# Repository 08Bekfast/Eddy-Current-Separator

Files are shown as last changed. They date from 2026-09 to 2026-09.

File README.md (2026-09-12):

# Miniaturized Eddy Current Separator

A compact, conveyor-based prototype for automatically separating non-ferrous metals from mixed material streams using electromagnetic induction.

**Project period:** November 2024 - January 2025  

<p align="center">
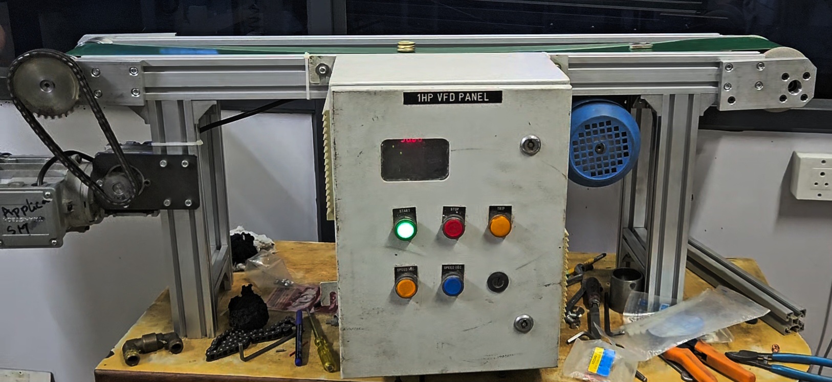
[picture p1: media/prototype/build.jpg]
Fabricated components and magnetic roller assembly
  
</p>

## How it works

Material travels along a conveyor and passes over a high-speed permanent-magnet rotor. The rotor produces a rapidly changing magnetic field, which induces eddy currents in conductive, non-ferrous pieces. Their opposing magnetic field creates a repulsive force, throwing them farther than non-conductive material and enabling physical separation.

## System overview

| Subsystem | Implementation |
|---|---|
| Structure | Aluminium extrusion frame with machined brackets and bearing mounts |
| Separation | Magnetic rotor inside a smooth PVC outer shell beneath a PU-coated conveyor belt |
| Drivetrain | Two three-phase motors, chain/sprocket transmission, 15:1 gearbox, and 1 HP VFD |
| Sensing | 20 kg load cell, HX711 amplifier, ultrasonic bin-level sensor |
| Control and telemetry | Arduino Uno, HC-05 Bluetooth module, and MIT App Inventor interface |
| Mechanical design | AutoCAD fabrication drawings and Fusion 360 component models/renders |

## Test results

Tests used approximately 1 cm² samples with a thickness of 1 mm.

| Material | Density (g/cm³) | Conductivity (MS/m) | Measured throw distance (m) |
|---|---:|---:|---:|
| Aluminium | 2.7 | ~37 | 1.25-1.70 |
| Copper | 8.96 | ~58 | 1.00-1.60 |
| Brass | ~8.5 | ~15 | 0.90-1.50 |

The prototype separated aluminium, copper, and brass samples in multiple shapes, including plates, rings, spheres, and folded wire. Thicker copper pieces were less consistent because their higher mass required greater ejection force. The sensing subsystem also delivered calibrated, real-time weight readings to the mobile app.

## CAD previews

| Outer-shell flange | Magnetic-roller shaft flange |
|---|---|
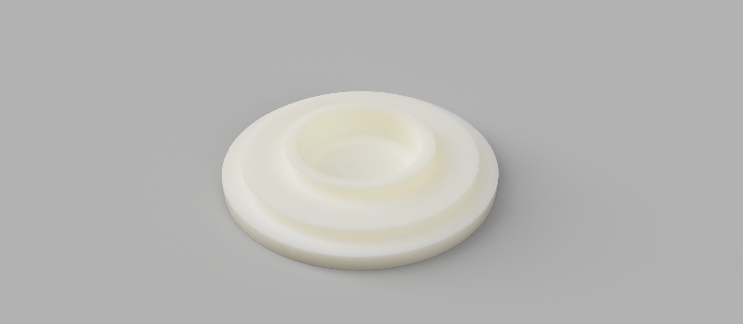
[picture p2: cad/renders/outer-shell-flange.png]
Outer-shell flange render
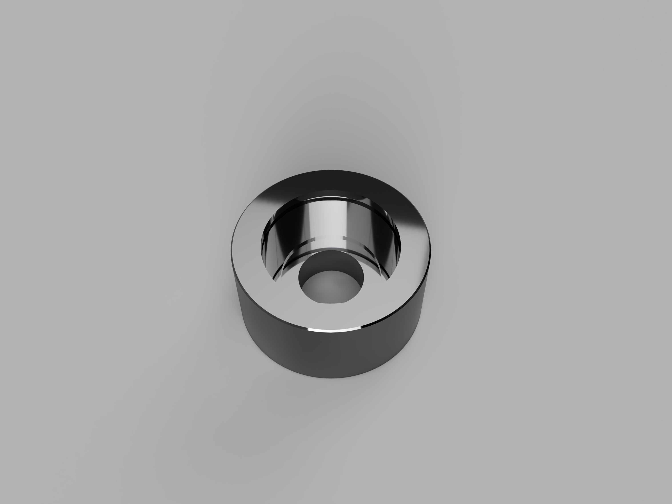
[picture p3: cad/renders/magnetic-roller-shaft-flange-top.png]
Magnetic-roller shaft flange render
|  |  |

| Shaft flange underside | Magnetic-shaft side bracket |
|---|---|
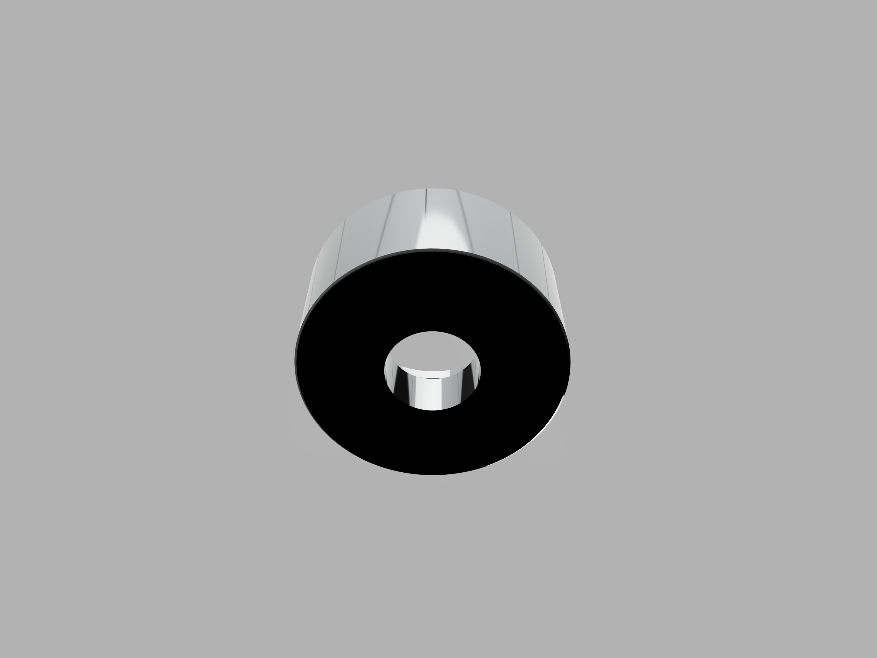
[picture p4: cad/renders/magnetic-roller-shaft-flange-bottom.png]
Shaft flange underside
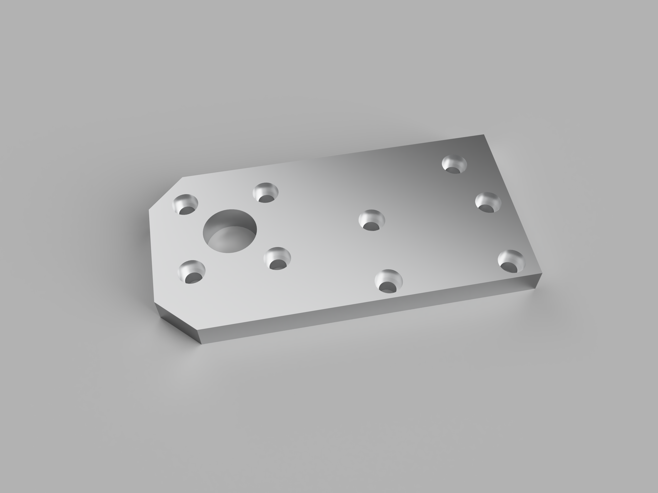
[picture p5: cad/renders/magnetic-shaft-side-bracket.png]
Magnetic-shaft side bracket
|  |  |

## Prototype gallery

The current gallery contains the fabrication and component collage above. Add final assembly, operating, and sorted-output photographs to [`media/prototype`](media/prototype/) using the guide in that folder.

## Repository contents

```text
.
├── cad/
│   ├── drawings/       # Eight dimensioned fabrication drawings
│   ├── models/         # Placeholder for native/neutral 3D CAD exports
│   ├── renders/        # Fusion 360 component renders
│   └── source/         # Original AutoCAD DWG
├── media/prototype/    # Physical build photographs
└── README.md
```

- [Full project report](docs/project-report.pdf)
- [CAD file guide](cad/README.md)
- [3D model upload guide](cad/models/README.md)
- [Original AutoCAD drawing](cad/source/eddy-current-separator.dwg)

## Future improvements

- Switch to an Electromagnet based system
- Measure separation efficiency, purity, throughput, and power consumption over larger test sets.

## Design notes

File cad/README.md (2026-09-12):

# CAD files

## Source

- `source/eddy-current-separator.dwg` - original AutoCAD drawing supplied for the project.

## Fabrication drawings

1. Magnetic roller shaft
2. Belt drive roller
3. PVC outer shell
4. Nylon outer-shell flange
5. Magnetic roller shaft flange
6. Idle roller flange
7. Magnetic roller right-side bracket
8. Magnetic roller left-side bracket

## Renders

The `renders/` folder contains Fusion 360 images of the outer-shell flange, magnetic roller shaft flange, and magnetic-shaft side bracket.

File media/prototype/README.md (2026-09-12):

# Prototype photo guide

The supplied fabrication collage is already used in the main README. For a stronger GitHub portfolio, add three landscape photographs here:

1. `completed-separator.jpg` - clean three-quarter view of the entire machine.
2. `separator-operating.jpg` - conveyor and magnetic roller during a test.
3. `separated-output.jpg` - input samples and the resulting material streams.

After adding them, uncomment the prepared image links in the main `README.md`.

Avoid showing personal information, workshop paperwork, or unsafe operation in the frame.

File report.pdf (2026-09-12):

# Eddy Current Separator

### Design, Fabrication, and IoT-Integrated Real-Time Monitoring System

Engineering Documentation & Technical Specification

Abstract — This technical report documents the design, fabrication, and experimental evaluation of a modular, benchtop-scale Eddy Current Separator (ECS) equipped with an integrated real-time Internet of Things (IoT) monitoring system. Eddy current separation leverages alternating magnetic fields induced by a high-speed permanent magnet rotor to generate opposing Lorentz forces in conductive non-ferrous particles, deflecting them away from non-conductive and ferrous bulk streams. The prototype integrates an adjustable conveyor drive system, an internal insulated permanent magnet rotor assembly, and an embedded sensing subsystem utilizing an Arduino microcontroller, an HX711-amplified load cell for continuous material mass logging, and an ultrasonic sensor for bin level monitoring. Telemetry is streamed wirelessly via an HC-05 Bluetooth transceiver to a dedicated Android supervisory dashboard. Empirical tests performed on aluminum, copper, and brass test specimens validate separation deflections between 0.9 m and 1.7 m. A comprehensive breakdown of mechanical drafting, bill of materials, circuit topology, assembly procedures, operational bottlenecks, and resolutions is provided to support open reproducibility.

December 2024

Open-Source Hardware Documentation Archive

### Contents

1 Introduction | 1
2 Problem Definition | 1
3 Literature Review | 2
4 Project Objectives | 3
5 System Architecture and Methodology | 3
6 Engineering Tools and Techniques | 4
7 Prototype Fabrication and Mechanical Assembly | 6
8 Electronics, Sensing, and Supervisory App | 9
9 Experimental Results and Discussion | 12
10 Conclusion and Future Scope | 13

i

Eddy Current Separator — Engineering Documentation | Technical Report

### 1 Introduction

### 1.1 Background

Industrial waste segregation and resource recovery represent critical challenges in municipal and scrap management ecosystems worldwide. Projected global municipal solid waste generation is expected to rise by over 70% by 2050. Despite the urgent need for recycling, low recovery rates persist in developing regions due to financial and operational constraints. Recovering recyclable commodities—particularly high-value non-ferrous metals such as aluminum, copper, and brass—dramatically reduces the energy consumption and carbon footprint associated with primary metal smelting and raw ore extraction.
Automating the recovery process eliminates human exposure to sharp, contaminated, or hazardous waste fragments while boosting processing throughput. Effective separation at the source also curbs downstream landfill overflow and preserves critical metallic reserves.

### 1.2 Working Principle of Eddy Current Separation

An Eddy Current Separator (ECS) operates on the physical principles of Faraday’s Law of Electromagnetic Induction and the Lorentz force equation. When a time-varying magnetic field interacts with an electrically conductive non-ferrous material, eddy currents are induced within the body of the material:
∇ × E = −

∂B
∂t | (1)
J = σ(E + v × B) | (2)

where B is the magnetic flux density, E is the induced electric field, σ is the electrical conductivity, and J is the induced eddy current density.
These circulating currents generate an intrinsic opposing secondary magnetic field in accordance with Lenz’s Law. The interaction between the external magnetic field gradients and the induced eddy currents produces a net repulsive Lorentz force:

F =

Z

V

(J × B) dV | (3)

In an ECS, a high-speed rotor lined with alternating polarity permanent magnets rotates within a non-metallic shell at the discharge head of a conveyor belt. As a mixed waste stream approaches the discharge pulley, non-conductive materials (such as plastics, wood, and glass) fall freely along a natural parabolic gravitational trajectory. In contrast, conductive non-ferrous particles experience an intense repulsive trajectory kick that throws them forward over an adjustable splitter blade into an isolated collection vessel.

### 1.3 Contribution to the Metal Recycling Industry

Eddy current separators are ubiquitous in municipal waste recycling, electronic scrap (e-waste) processing, automobile shredder residue (ASR) recovery, and foundry sand cleanup. Commercial ECS systems routinely achieve non-ferrous metal recovery rates of up to 95%, substantially decreasing dependency on virgin mining operations, cutting landfill disposal surcharges, and improving the economic yield of recycling facilities.

### 2 Problem Definition

### 2.1 Problem Statement

“Inefficient waste management in developing industrial contexts is exacerbated by the absence of localized, modular non-ferrous metal separation machinery. By integrating real-time telemetry and sensing frameworks into an automated separator, facility managers can monitor mass recovery rates, optimize operational parameters, and enhance scalability.”

### 2.2 Key Industrial Challenges

Conventional sorting facilities face several structural bottlenecks:

### 1. Loss of Recoverable Non-Ferrous Metals: Manual or low-field sorting systems fail to

capture small particles and non-magnetic conductive fragments, dumping valuable raw stock into landfills.

### 2. High Human Labor Dependency and Low Sorting Efficiency: Manual hand-

picking suffers from low throughput, worker injury risks from hazardous contaminants, and inconsistent purity yields.

### 3. Absence of Real-Time Operational Feedback: Traditional scrap sorting machines

operate as open-loop units without automated logging of collected weight, capacity status, or material throughput.

### 3 Literature Review

A review of recent academic literature and technical patents informed the physical architecture and telemetry systems of this project, as summarized in Table 1.

Table 1: Summary of Surveyed Literature and Project Relevance

Paper Title | Author /
Year
Key Findings | Project Relevance

Effect of eddy currents on metal fine
particles in high gradient magnetic separation using a superconducting magnet
H. Chen & O.
Miura (2024)

Investigated dry highgradient magnetic separation for fine metallic
particles. Demonstrated
that capture efficiency is strongly governed by particle dimensions, material conductivity, and rotor
field dynamics.

Supplied baseline deflection criteria across aluminum, copper, and precious metals, underscoring the influence of rotor rotational velocity.

Separation of copper
from aluminum in an
eddy current separator product by dry
density separation
M. Ali (2024) Analyzed fluidized bed and pneumatic density separation methods to isolate Cu from Al post- ECS sorting. Evaluated efficiency against manual sorting and XRF valida- tion. Informed downstream
collection architecture,
showing that high-density
non-ferrous scrap requires secondary density classification or increased field strength.

Continued on next page. . .

Table 1 continued from previous page
Paper Title | Author /
Year
Key Findings | Project Relevance

Experiment sorting
of non-ferrous metals by new orientation of magnetic disk
separator
K. Nadjib et
al.

Modeled an alternative
single-disk vertical ECS
architecture using alternating permanent magnets. Quantified the relationship between disk
speed, particle geometry,
and ejection trajectory.

Offered structural insights into drum configurations,
magnetic pole spacing,
and speed ratios between
drive pulleys and internal rotors.

Digitalization and intelligent robotics in
value chain of circular economy oriented
waste management
R. Sarc et al. Explored Industry 4.0 paradigms (ReWaste
4.0) integrating sensory
| digitization, automated robotics, and real-time level/weight acquisition for supply chain optimiza- tion.

Guided the selection of an IoT sensory stack (load
cell, ultrasonic sensor,
Bluetooth telemetry) for
live collection bin monitoring.

### 4 Project Objectives

### 4.1 Primary Objective

To design, engineer, and validate a fully functional benchtop prototype of an Eddy Current Separator capable of separating non-ferrous metallic fragments (Al, Cu, Brass) from non-conductive municipal/industrial waste.

### 4.2 Specific Technical Objectives

- Mechanical Framework: Fabricate a rigid, vibration-isolated aluminum extrusion chassis housing independent drive belts and a high-speed magnetic rotor.
- Independent Speed Control: Implement dual motor drives managed via a Variable Frequency Drive (VFD) and reduction gearing to optimize sorting efficiency.
- Real-Time Mass Logging: Integrate a 20 kg strain-gauge load cell and 24-bit HX711 ADC to quantify recovered scrap weight dynamically.
- Bin Level Monitoring: Integrate an ultrasonic time-of-flight sensor to detect container overflow thresholds.
- Wireless Supervisory Interface: Develop an Android dashboard application for real-time visualization of sorting metrics and automated bin-full alerts.

### 5 System Architecture and Methodology

The system engineering workflow followed an iterative path from conceptual sketching, Computer-Aided Design (CAD), finite sizing calculations, component fabrication, sensory electronics integration, to validation trials (Figure 1).

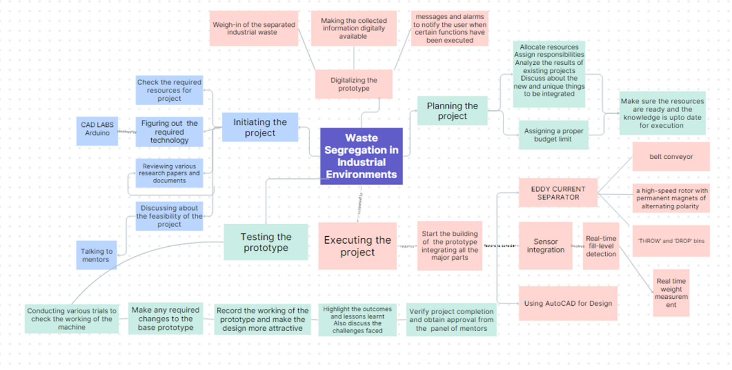
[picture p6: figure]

Figure 1: System architecture and project execution workflow spanning conceptualization, mechanical fabrication, sensor integration, and validation.

### 5.1 Design Phase

- 2D Mechanical Drafting: Detailed part drawings and dimensional tolerances were created in AutoCAD to guide machine-shop turning and milling operations.
- 3D Parametric Modeling: Complete 3D virtual assemblies were modeled in Autodesk Fusion 360 to verify bearing seat alignments, motor mounting clearances, and center-ofgravity balance.
- Circuit Simulation: Embedded sensor networks and signal conditioners were prototyped and verified in Autodesk TinkerCAD before breadboard soldering.

### 5.2 Component Procurement and Material Selection Rationale

Materials were selected based on structural rigidity, electromagnetic neutrality, wear resistance, and cost effectiveness:
- Extruded Aluminum Profiles (30×30): Chosen for high strength-to-weight ratio, structural modularity, and zero magnetic interference.
- En-8 Carbon Steel (Zinc Coated): Used for drive shafts and roller flanges to ensure high torsional shear strength and corrosion protection.
- Nylon Outer Shell Flanges: Non-conductive, low-dielectric polymer sleeves prevent eddy current self-heating within structural endplates.
- Smooth PVC Pipe Drum Sleeve: Acts as an electromagnetic barrier and physical shield, isolating the high-speed internal rotor from the slower outer conveyor belt.
- PU-Coated Belt: Durable, anti-static, heat-resistant conveyor belt ensuring stable material transport without erratic slip.

### 6 Engineering Tools and Techniques

### 6.1 Software Toolchain

1. AutoCAD: Used for 2D drafting of precision shafts, bracket mountings, and flange bolt patterns.
2. Autodesk Fusion 360: Used for 3D modeling, dynamic collision checks, and parametric rendering (Figure 2).

3. Arduino IDE: Used to write, compile, and flash embedded C++ firmware onto the microcontroller.
4. Autodesk TinkerCAD: Provided circuit schematics and breadboard validation for sensor amplifier logic.
5. MIT App Inventor: Visual blocks platform used to construct the responsive Android monitoring application.

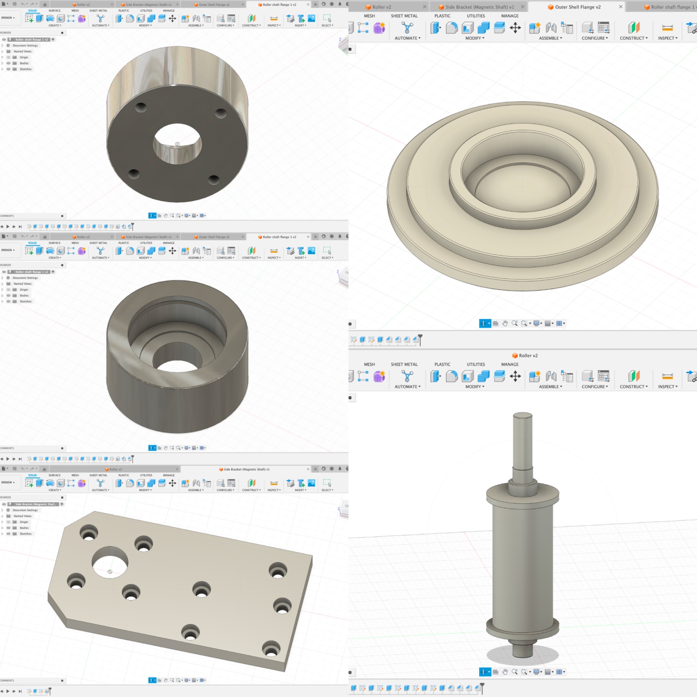
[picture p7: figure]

Figure 2: Autodesk Fusion 360 parametric 3D models and renders of custom-fabricated components (roller shaft flanges, nylon outer sleeves, and bearing brackets).

### 6.2 Hardware and Sensory Stack

- Microcontroller (Arduino Uno): ATmega328P core running at 16 MHz, orchestrating sensor sampling and serial packet streaming.
- Load Cell (20 kg Parallel Beam): Strain gauge transducer converting mechanical deflection into proportional differential millivolt signals.
- HX711 Instrumentation Amplifier: 24-bit high-precision analog-to-digital converter configured with an internal low-noise programmable gain amplifier (PGA gain = 128).
- HC-SR04 Ultrasonic Sensor: Emits 40 kHz ultrasonic pulses to measure the distance to the accumulated scrap pile in the bin.
- HC-05 Bluetooth Module: Serial Port Profile (SPP) transceiver transmitting weight and status strings at 9600 baud.

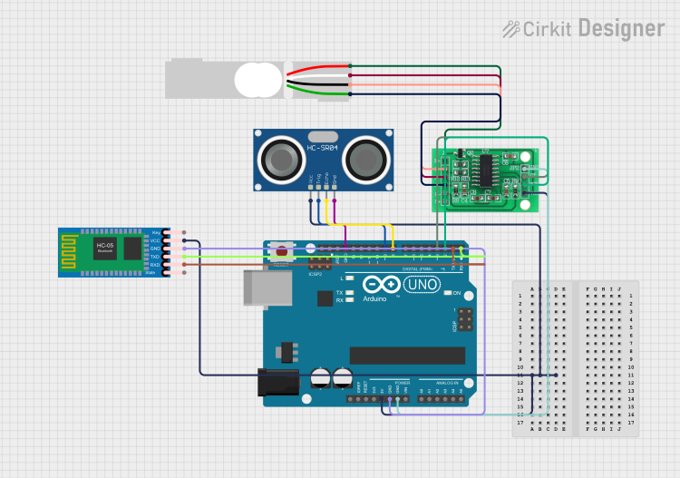
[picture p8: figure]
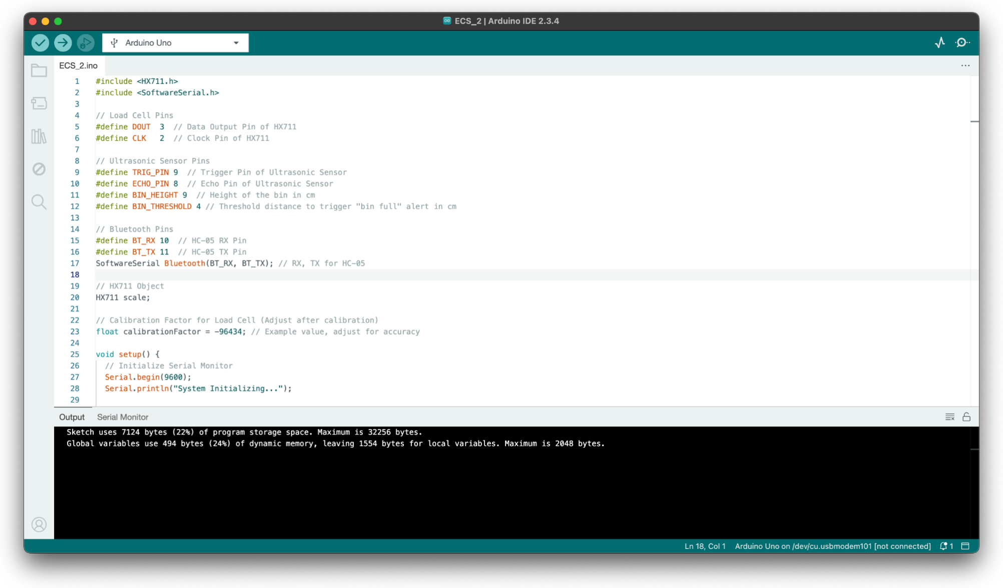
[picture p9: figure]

(a) TinkerCAD virtual circuit simulation. | (b) Arduino IDE firmware environment.

Figure 3: Embedded hardware simulation and software implementation environment.

### 7 Prototype Fabrication and Mechanical Assembly

### 7.1 Bill of Materials and Component Classification

Table 2 outlines the standard off-the-shelf, custom-machined, and miscellaneous parts incorporated into the physical build.

Table 2: Comprehensive Bill of Materials (BOM) and Component Classification

Category | Component | Material / Technical Specifica- tion

Off-the-Shelf Parts

Aluminum Profiles | 30 × 30 mm modular extruded alu-
| minum
Deep Groove Ball Bearings | HCH IATF 16949:2016 certified
| bearings
Circlips | High-carbon spring steel (Types A,
| B, and E)
Industrial Belt | Static-dissipative, heat and tear re-
| sistant
Fasteners | M6 Allen bolts with top-loading
| Slot-8 T-nuts
Structural Brackets | 30 × 30 mm Die-cast aluminum angle
| brackets
Drive Sprockets & Pulleys | Industrial machined steel
Drive Chains | Precision linking roller chain

Custom Fabricated

Support Brackets | Machined 6082-T6 structural alu-
| minum
Roller Shaft Flange | En-8 high-strength steel (Zinc-
| plated)
Idle Roller Flange | En-8 high-strength steel (Zinc-
| plated)
Outer Shell Flange | CNC-turned wear-resistant Nylon

Drive & Assemblies

High-Speed Magnetic Rotor | Multi-pole NdFeB permanent mag-
| nets salvaged from servo rotor
Drum Outer Sleeve | Schedule-40 non-magnetic PVC pipe
Material Conveyor Belt | Heavy-duty polyurethane (PU)
| coated belt
Safety Enclosures | Sheet metal chain and belt guards
Speed Reduction Gearbox | 15:1 ratio worm-reduction unit
Three-Phase Induction Motors | 2790 RPM rated industrial induction
| motors

### 7.2 Assembly Sequence

The physical separator was constructed and commissioned over an 18 man-hour assembly window across three days:
1. Mainframe Construction: Rigid 30 × 30 extruded aluminum sections were assembled using gussets and T-nuts, providing an adjustable modular base frame.
2. Bearing Block & Bracket Installation: Custom-machined aluminum side brackets were anchored to the frame, ensuring axial alignment across both primary shafts.

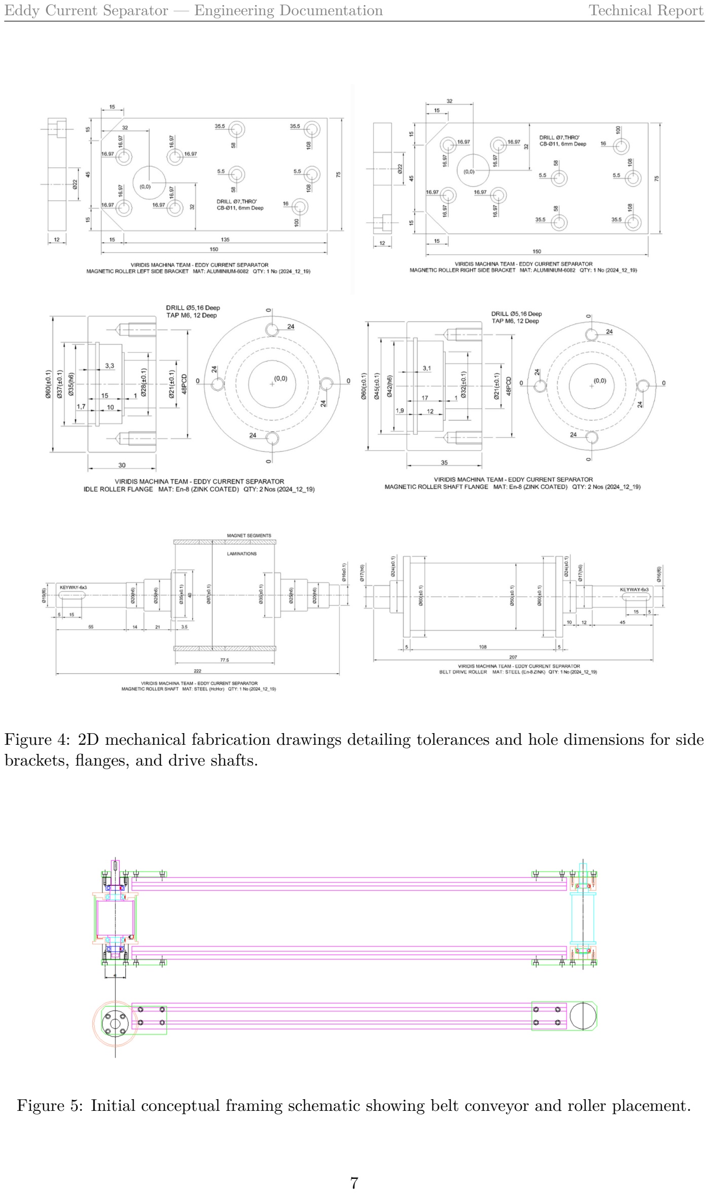
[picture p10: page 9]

Figure 4: 2D mechanical fabrication drawings detailing tolerances and hole dimensions for side brackets, flanges, and drive shafts.

Figure 5: Initial conceptual framing schematic showing belt conveyor and roller placement.

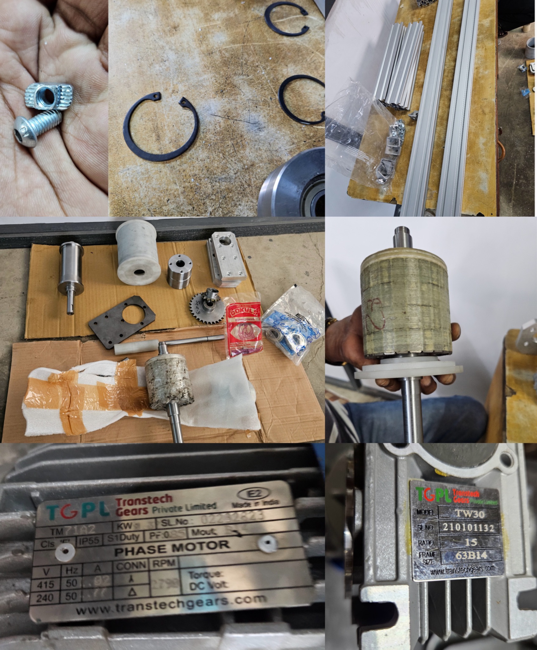
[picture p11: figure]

Figure 6: Procured hardware components, aluminum extrusion framing, bearings, fasteners, motor, and machined mechanical parts.

3. Magnetic Rotor Isolation Sleeve: A non-conductive PVC cylinder was machined to house the inner high-speed magnetic rotor, mechanically isolating its rotation from the outer conveyor drum.
4. Roller and Conveyor Belt Fitting: Bearings were seated into the end flanges, the PU conveyor belt was looped over the pulleys, and tension was balanced to prevent tracking wander.
5. Motor Flange Mounting: Two AC motors were mounted via B14 flange plates directly onto the extrusion channels.
6. Chain Drive Transmission: Keyed sprockets were locked onto the motor and drum shafts; roller chains were installed with proper slack tension.
7. VFD Electrical Integration: A single-phase to three-phase Variable Frequency Drive (VFD, 1 HP) was wired in a star configuration to govern motor speeds accurately.
8. Dynamic Alignment and Tuning: Belt tracking was tuned, rotational vibration was dampened, and electrical interlocks were calibrated.

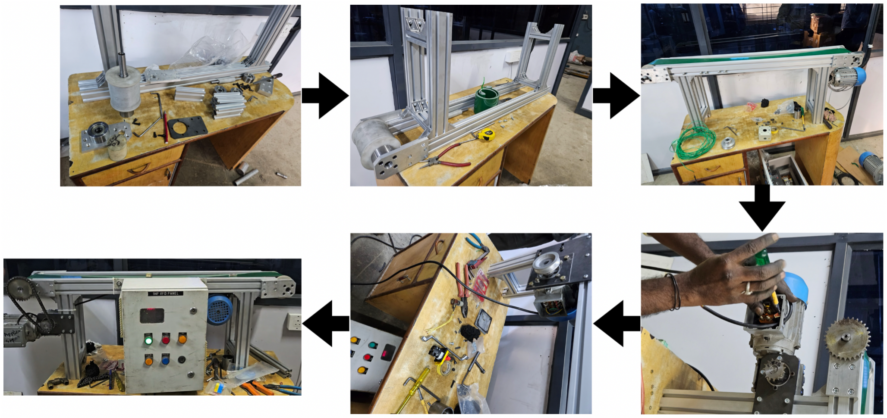
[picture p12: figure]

Figure 7: Step-by-step photographic record of frame erection, motor mounting, transmission fitting, and electrical cabinet wiring.

### 7.3 Engineering Challenges and Practical Resolutions

During fabrication and mechanical commissioning, several technical issues were resolved:

### 1. Hardware Quantity Underestimation: T-nuts and M6 socket cap screws were con-

sumed rapidly; a centralized stock of fasteners was procured to avoid future stoppages.

### 2. Missing B14 Motor Flange Adapter: The specific motor flange was out of stock. Two

steel plates were CNC milled and dowel-pinned together to produce a custom adapter plate.

### 3. Conveyor Belt Tracking Sag: Uneven tension caused belt wandering and friction

against the side frame. Adjustable tensioning slots were machined into the idler roller brackets.

### 4. Drive Motor Power Insufficiency: The original 1478 RPM motor lacked sufficient

centrifugal torque for high-speed rotor excitation. It was upgraded to a ∼ 3000 RPM induction motor.

### 5. VFD Single-to-Three Phase Wiring Complexity: Industrial three-phase motors were

adapted to single-phase utility mains by configuring stator windings in star configuration across a compact 1 HP inverter drive.

6. Conveyor Linear Speed Mismatch: A 7.5 : 1 gearbox ran the conveyor too fast, launching materials off the belt prematurely. Replacing it with a 15 : 1 reduction gearbox achieved optimal linear feed speed.

### 7. Chassis Leveling and Axial Runout: Misaligned bearing blocks consumed 2 hours of

realignment. Dial indicators and precision spirit levels were employed to ensure coaxial rotation.

### 8. Material Ejection Containment: Scattered fragments occasionally bounced off the

belt; transparent polycarbonate side skirts were affixed above the conveyor.

### 9. High-Speed Operator Safety: Rapidly rotating sprockets and chains represented pinch

hazards; sheet metal chain guards and emergency stop pushbuttons were added.

### 8 Electronics, Sensing, and Supervisory App

### 8.1 Circuit Topology and Pinout

The electronic subsystem connects the sensing elements to the central Arduino Uno microcontroller, as mapped in Table 3 and illustrated in Figure 8.

### 8.2 Load Cell Signal Conditioning and Calibration

The parallel beam load cell generates differential signals on the order of ±20 mV. The HX711 integrates this signal with a 24-bit Σ-∆ ADC:
1. Raw Zero-Load Offset: The uncalibrated analog offset produced an initial raw ADC value of −7050.
2. Known Reference Calibration: Applying calibrated test masses (1.000 kg and 2.500 kg) allowed computation of the linear slope.
3. Final Calibration Factor: The finalized scaling multiplier was programmed as −96343, providing mass resolutions within ±10 grams.

Table 3: Microcontroller Pin Connections and Peripheral Interfacing

Arduino Uno Pin | Peripheral Module | Module Pin | Functional Description
Pin 2 | HX711 Amplifier | CLK | Serial Clock output for
| | | ADC conversion
Pin 3 | HX711 Amplifier | DOUT | Serial Data line for 24-bit
| | | weight reading
Pin 8 | HC-SR04 Ultrasonic | ECHO | Time-of-flight pulse echo
| | | input
Pin 9 | HC-SR04 Ultrasonic | TRIG | 10 µs ultrasonic pulse trig-
| | | ger
Pin 10 | HC-05 Bluetooth | TX | SoftwareSerial RX pin
Pin 11 | HC-05 Bluetooth | RX | SoftwareSerial TX pin (via
| | | resistor divider)
5V | All Peripherals | VCC | Regulated 5V DC system
| | | power bus
GND | All Peripherals | GND | Common ground reference

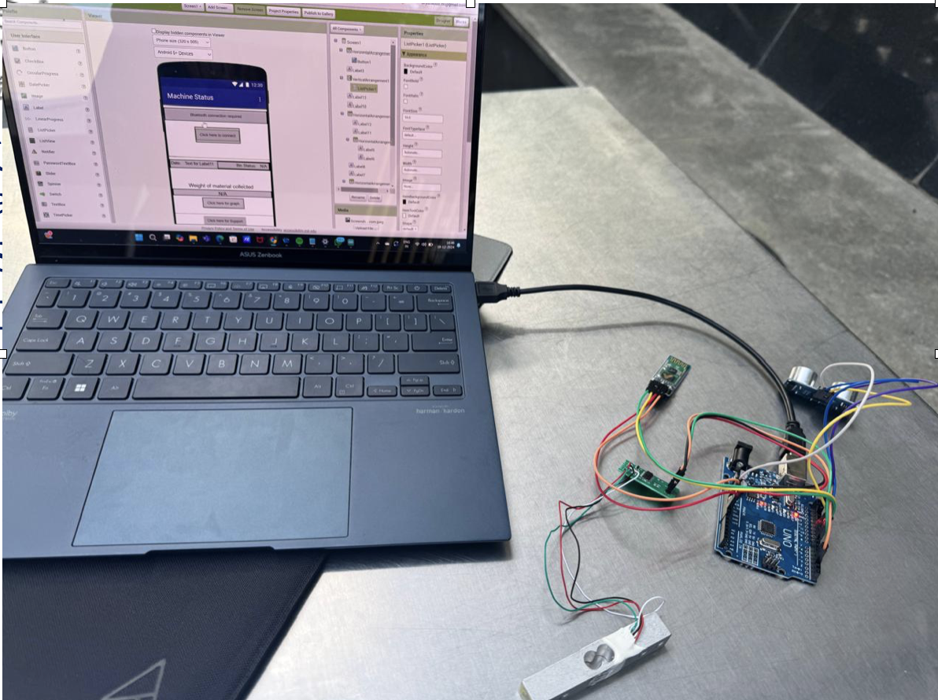
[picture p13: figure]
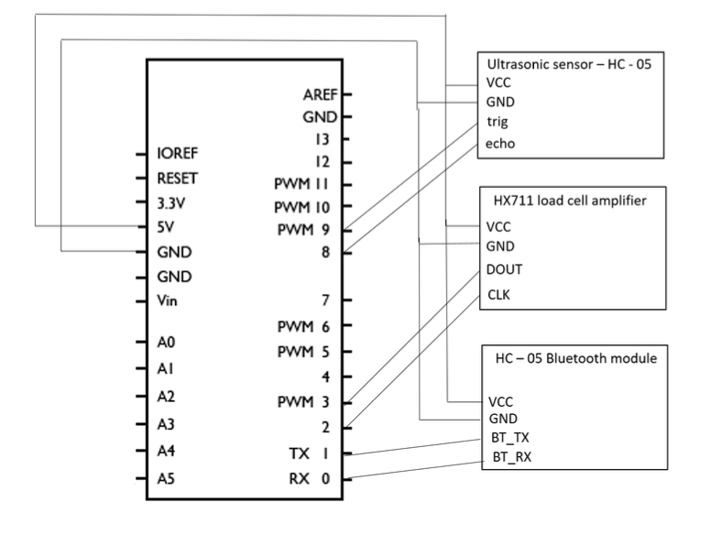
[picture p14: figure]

(a) Schematic pinout diagram. | (b) Physical breadboard and sensor test setup.

Figure 8: Electronic interfacing between Arduino Uno, HX711, ultrasonic transducer, and Bluetooth transceiver.

### 8.3 Firmware Implementation

The core Arduino control routine samples the load cell, computes distance thresholds, and formats a serial telemetry packet every second:

1 | # include < HX711 .h >
2 | # include < SoftwareSerial .h >

3
4 | # define DOUT | 3 | // Data Output Pin of HX711
5 | # define CLK | 2 | // Clock Pin of HX711
6 | # define TRIG_PIN | 9 | // Ultrasonic Trigger Pin
7 | # define ECHO_PIN | 8 | // Ultrasonic Echo Pin
8 | # define BIN_THRESHOLD 4 // Distance threshold in cm for " bin full "

9
10 | SoftwareSerial Bluetooth (10 , 11) ; // RX , TX for HC -05
11 | HX711 scale ;
12 | const float calibrationFactor = -96343.0;

13
14 | void setup () {
15 | Serial . begin (9600) ;
16 | Bluetooth . begin (9600) ;
17 | scale . begin ( DOUT , CLK ) ;
18 | scale . tare () ;
19 | scale . set_scale ( calibrationFactor ) ;
20 | pinMode ( TRIG_PIN , OUTPUT ) ;

21 | pinMode ( ECHO_PIN , INPUT ) ;
22 | }

23
24 | int getDistance () {
25 | digitalWrite ( TRIG_PIN , LOW ) ;
26 | delayMicroseconds (2) ;
27 | digitalWrite ( TRIG_PIN , HIGH ) ;
28 | delayMicroseconds (10) ;
29 | digitalWrite ( TRIG_PIN , LOW ) ;
30 | long duration = pulseIn ( ECHO_PIN , HIGH ) ;
31 | return duration * 0.034 / 2; // Convert to cm
32 | }

33
34 | void loop () {
35 | float weight = scale . get_units (10) ; // Average of 10 readings
36 | int distance = getDistance () ;
37 | bool binFull = ( distance <= BIN_THRESHOLD ) ;

38
39 | // Transmit telemetry over Bluetooth SPP
40 | Bluetooth . print (" Weight : ") ;
41 | Bluetooth . print ( weight , 2) ;
42 | Bluetooth . println (" kg ") ;
43 | Bluetooth . println ( binFull ? " Bin Status : FULL " : " Bin Status : OK ") ;

44
45 | delay (1000) ;
46 | }

Listing 1: Embedded Arduino firmware running on the ATmega328P controller.

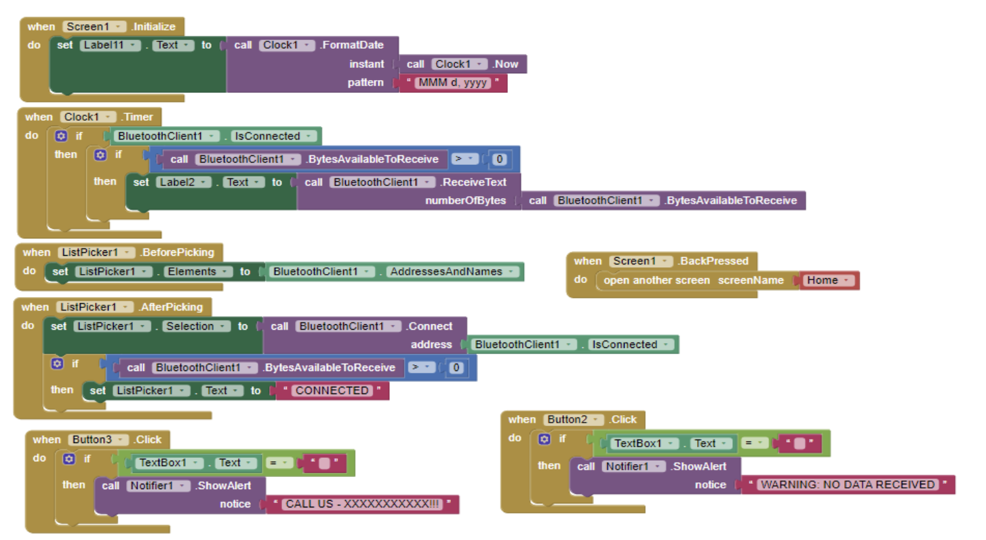
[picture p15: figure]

Figure 9: MIT App Inventor visual logic blocks handling Bluetooth SPP string parsing, timer events, and alert dialogs.

### 8.4 Supervisory Mobile Dashboard

The MIT App Inventor application was designed with automated reconnect routines to mitigate RF dropped packets. As displayed in Figure 10, the application transitioned from an early wireframe to a full supervisory telemetry interface featuring live weight display, distance-to-brim readouts, bin-full warnings, and cloud upload hooks.

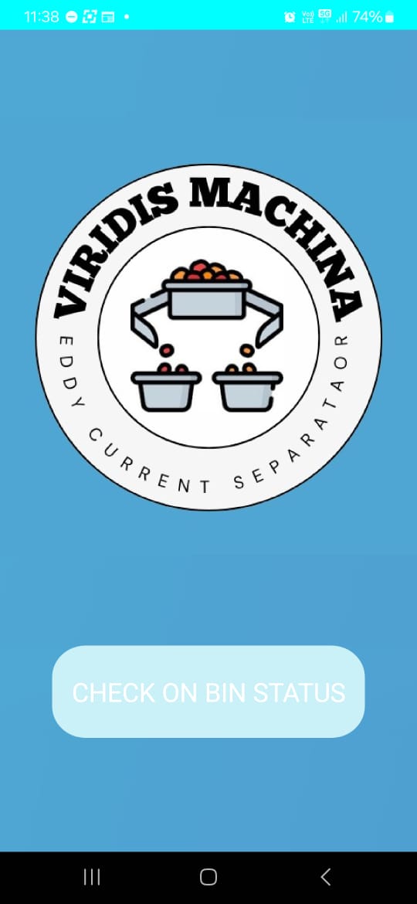
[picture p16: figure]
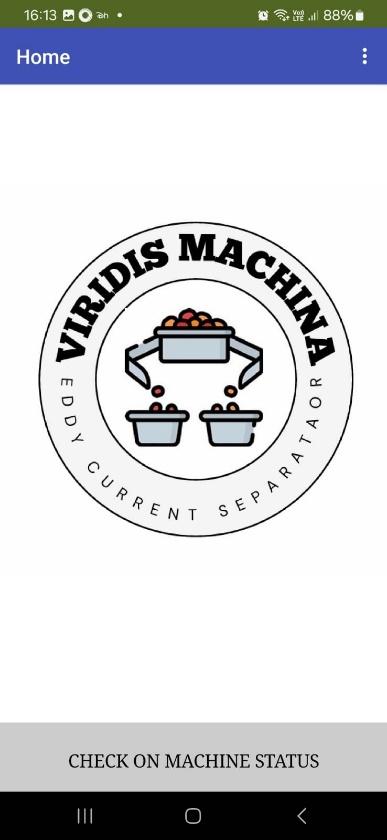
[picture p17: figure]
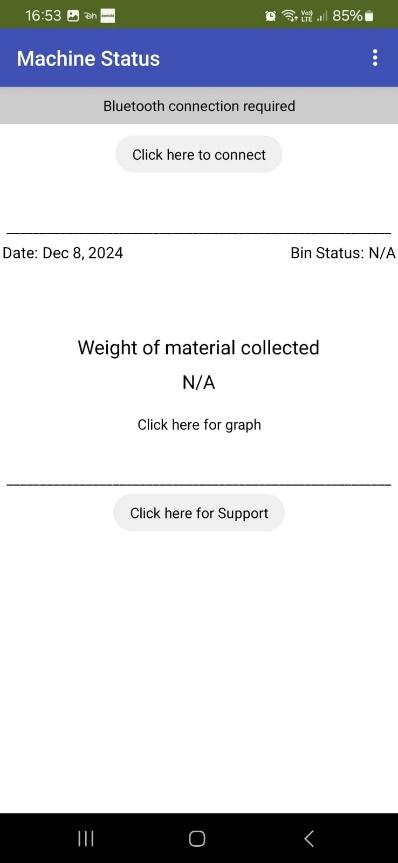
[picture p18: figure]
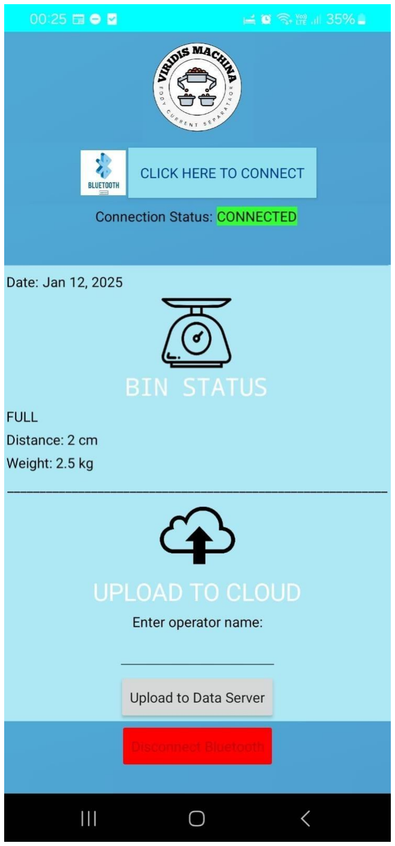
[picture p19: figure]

(a) Initial Splash | (b) Initial Status | (c) Final Splash | (d) Final Live UI

Figure 10: Evolution of the mobile monitoring app from early mockups to the final operational dashboard.

### 9 Experimental Results and Discussion

### 9.1 Non-Ferrous Separation Performance

Sorting experiments were carried out on uniform standardized test pieces (1 cm²
surface area,
1 mm thickness) fed continuously along the conveyor belt. The results are summarized in Table 4.

Table 4: Deflection Test Results Across Non-Ferrous Metallic Specimens (1 cm² × 1 mm)

Material | Density (g/cm³
) | Conductivity (MS/m) | Measured Throw Distance (m)
Aluminum | 2.70 | ∼ 37.0 | 1.25 – 1.70
Copper | 8.96 | ∼ 58.0 | 1.00 – 1.60
Brass | ∼ 8.50 | ∼ 15.0 | 0.90 – 1.50

### 9.2 Physical Dynamics and Lorentz Trajectory Analysis

The ejection trajectory of a non-ferrous particle in an ECS is governed by its conductivity-todensity ratio (σ/ρ):
- Aluminum (σ/ρ ≈ 13.7 k · m²/Ω · kg): Exhibits the highest throw distance (1.25–1.70 m) due to its low mass density relative to electrical conductivity. The magnetic repulsive force accelerates the particle clear of the discharge pulley.
- Copper (σ/ρ ≈ 6.5 k · m²/Ω · kg): Despite higher electrical conductivity (≈ 58 MS/m), copper’s substantial density (8.96 g/cm³
) increases gravitational pull, requiring greater repulsive Lorentz force. Thicker copper billets exhibited lower deflection.
- Brass (σ/ρ ≈ 1.8 k · m²/Ω · kg): Yielded the smallest throw distance (0.90–1.50 m), directly matching theoretical expectations due to lower alloy conductivity.
Geometry also influenced trajectory: planar flakes and hollow rings experienced higher induced eddy current loops and cleaner ejections compared to tightly coiled wires or thick ingots.

### 9.3 Telemetry and Weight Sensor Reliability

Continuous material drops onto the load-cell receiver bin demonstrated reliable linear response across 0.05 kg to 15.0 kg. The calibrated scale factor (−96343) maintained steady measurement stability without zero-drift during continuous 30-minute operational runs. Bluetooth packets were transmitted and refreshed once per second without noticeable UI latency on the mobile terminal.

### 10 Conclusion and Future Scope

### 10.1 Conclusion

This work successfully developed, assembled, and experimentally validated a benchtop Eddy Current Separator with an integrated IoT telemetry subsystem. The mechanical design achieved clean separation across aluminum, copper, and brass test fragments. Real-time mass logging and container capacity tracking operated robustly over a wireless Bluetooth connection. The resulting machine provides a low-cost, modular blueprint for automated non-ferrous recovery in localized scrap reclamation contexts.

### 10.2 Future Scope

- Automated Dynamic Splitter: Incorporating servo-actuated diverter plates controlled by computer vision or optical speed sensors to adjust splitter angles dynamically for mixed feed streams.
- Upstream Pre-Conditioning / Shredder Feed: Integrating an in-line mechanical rotary shredder to achieve uniform particle size distribution prior to belt loading.
- High-Flux Neodymium Rotors: Increasing rotor pole density and utilizing N52 grade NdFeB magnets to enable effective separation of heavy copper fragments and smaller sub-millimeter fines.
- Industrial IoT / MQTT Gateway: Upgrading the microcontroller to an ESP32 or Raspberry Pi to stream data directly to cloud-based dashboards (e.g., Grafana / AWS IoT) over Wi-Fi.

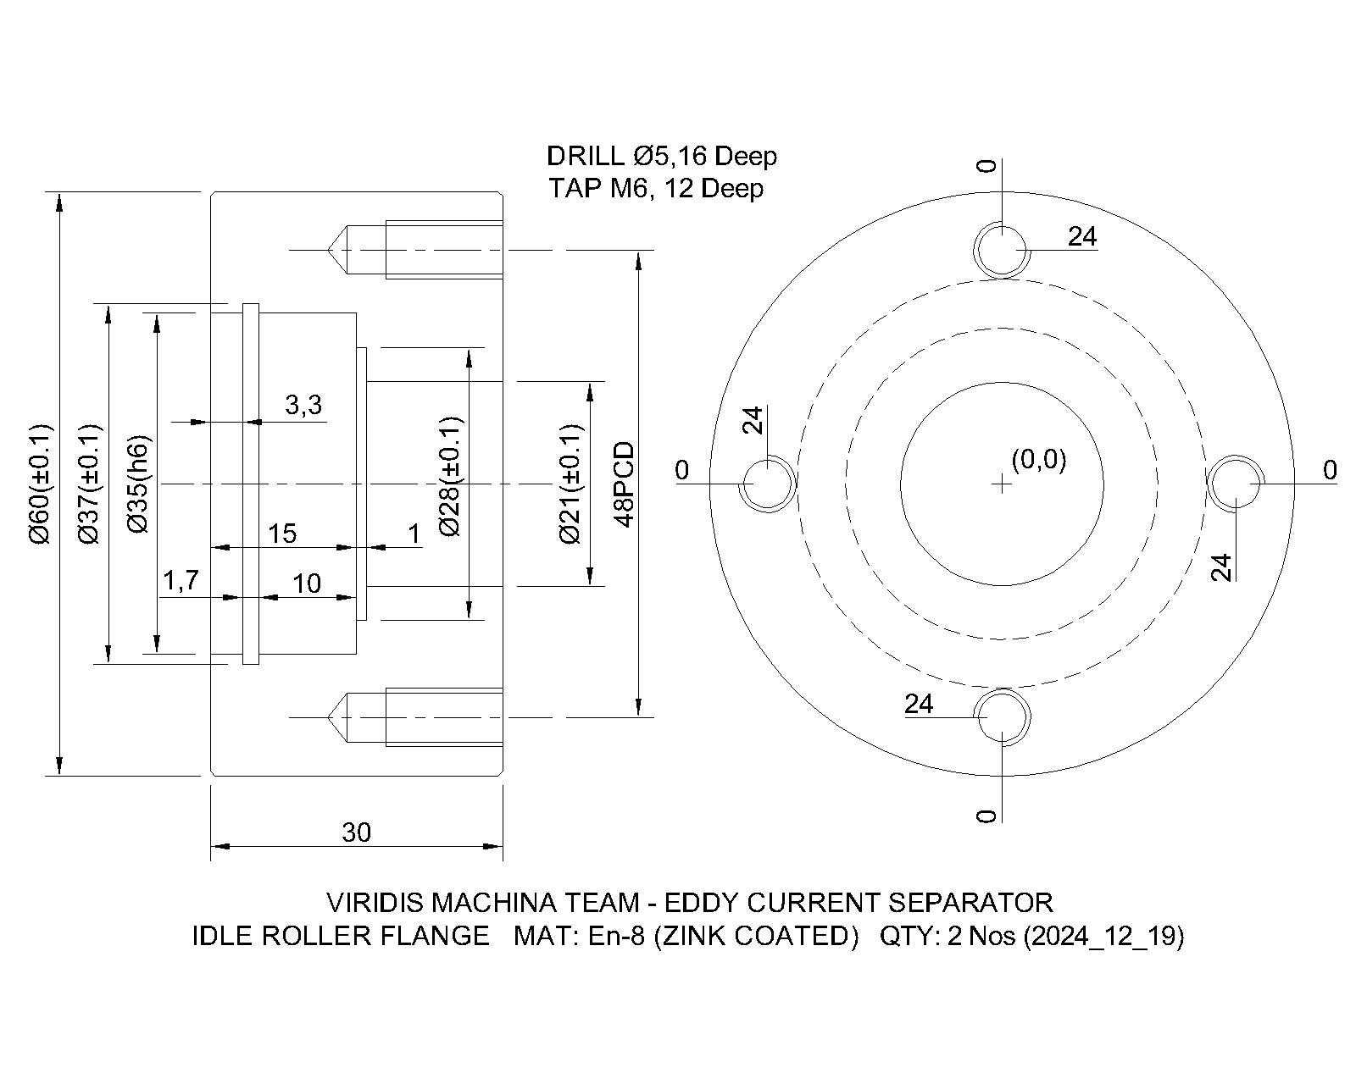
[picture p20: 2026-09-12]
cad/drawings/06-idle-roller-flange.png

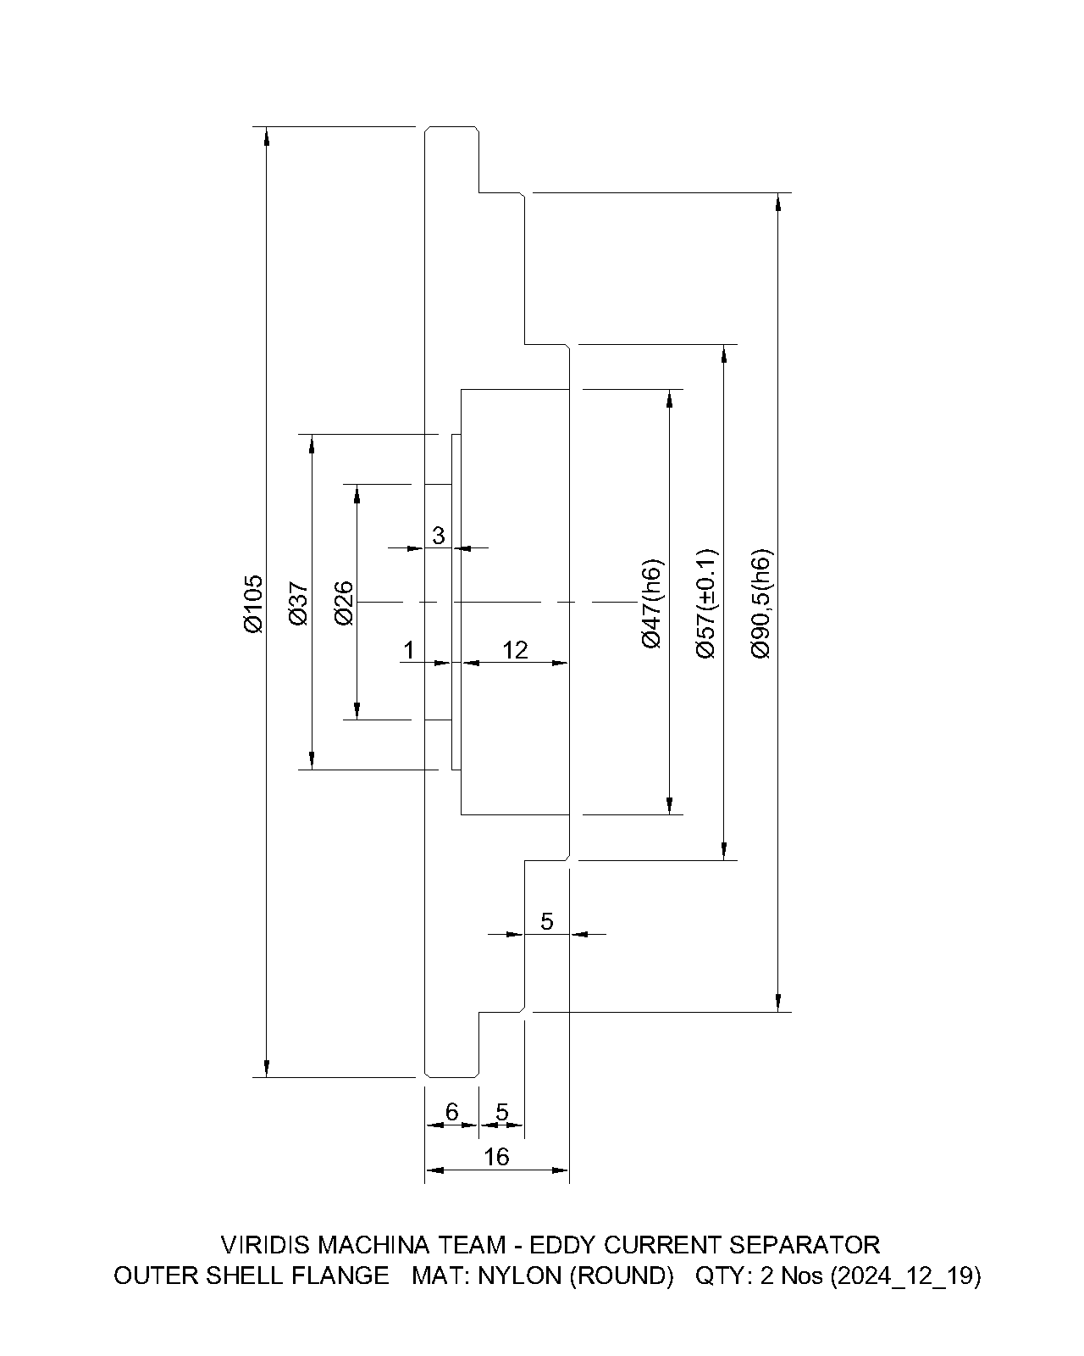
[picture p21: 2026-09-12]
cad/drawings/04-nylon-outer-shell-flange.png

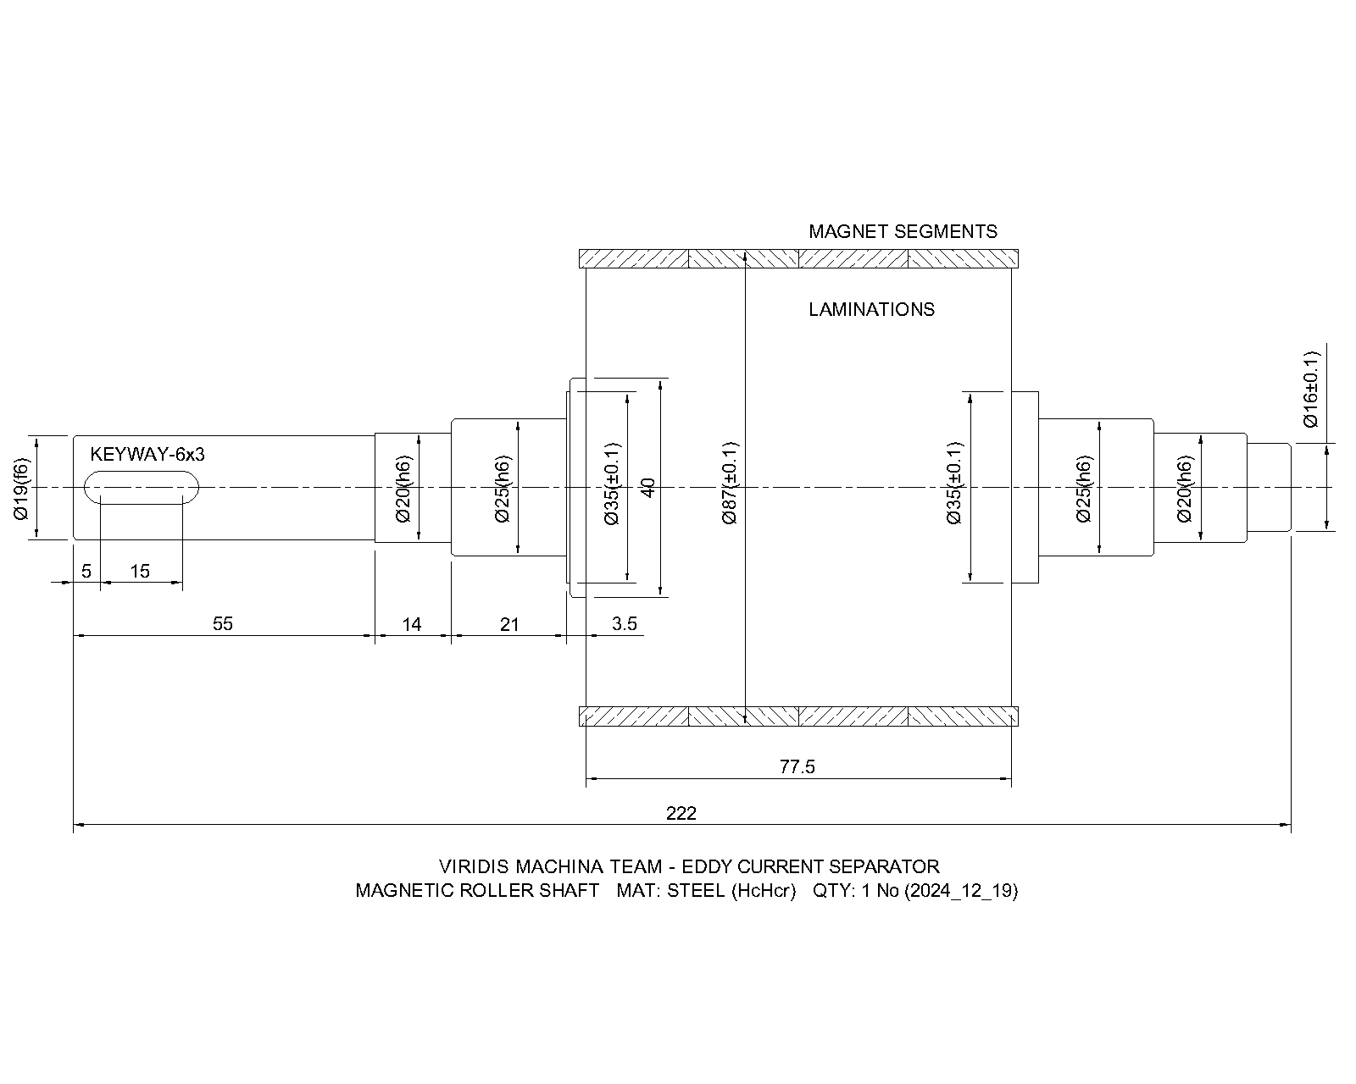
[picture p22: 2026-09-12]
cad/drawings/01-magnetic-roller-shaft.png

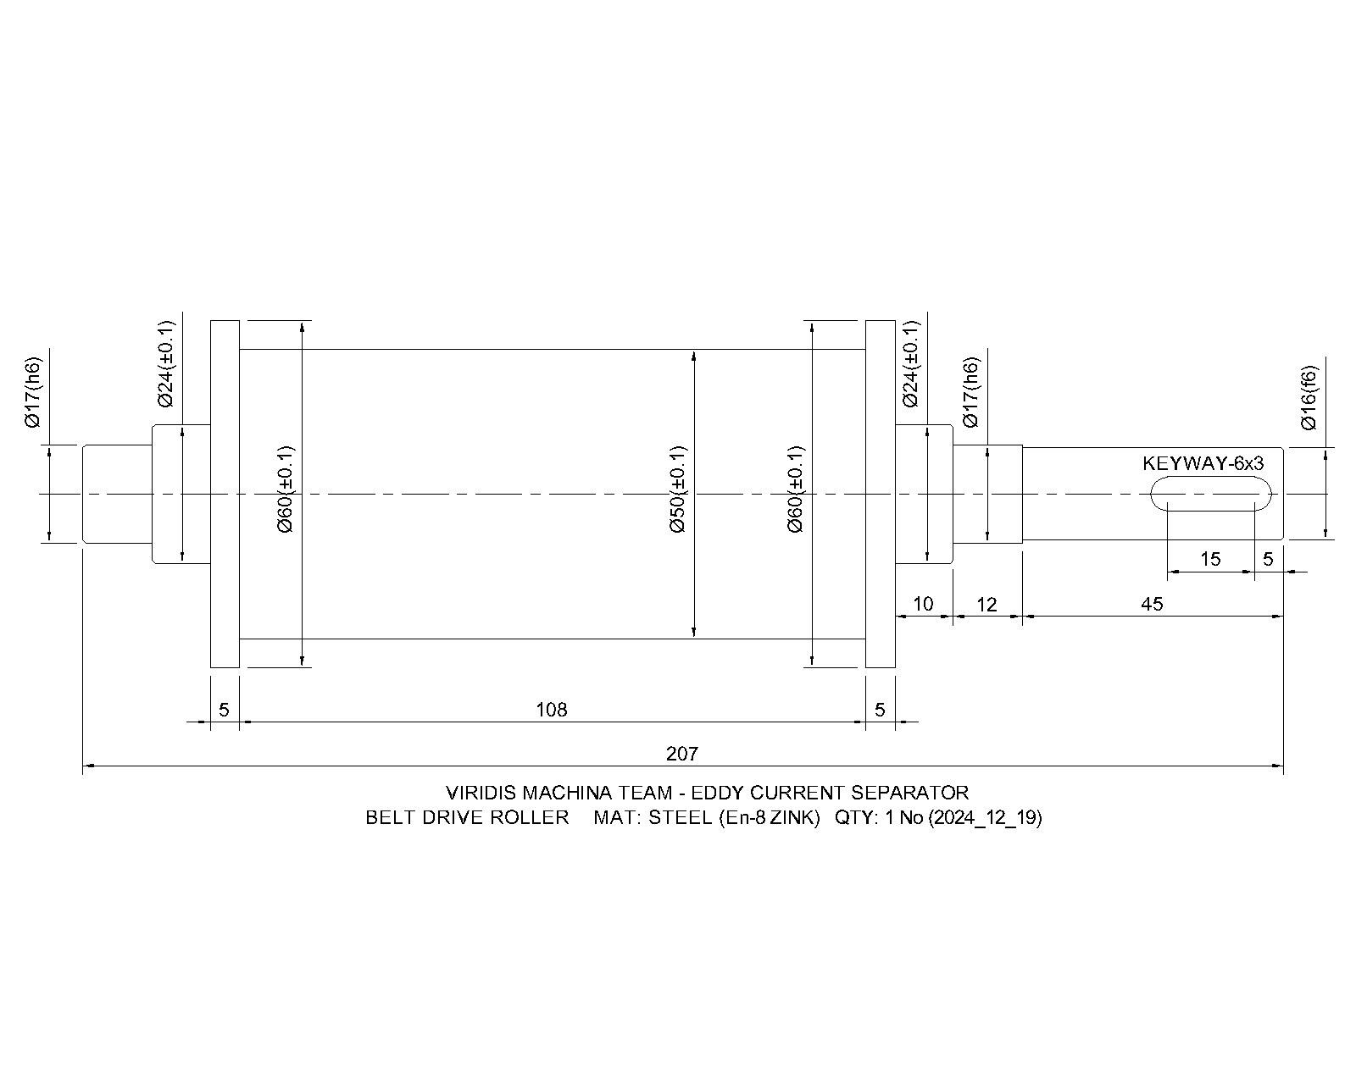
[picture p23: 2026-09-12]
cad/drawings/02-belt-drive-roller.png

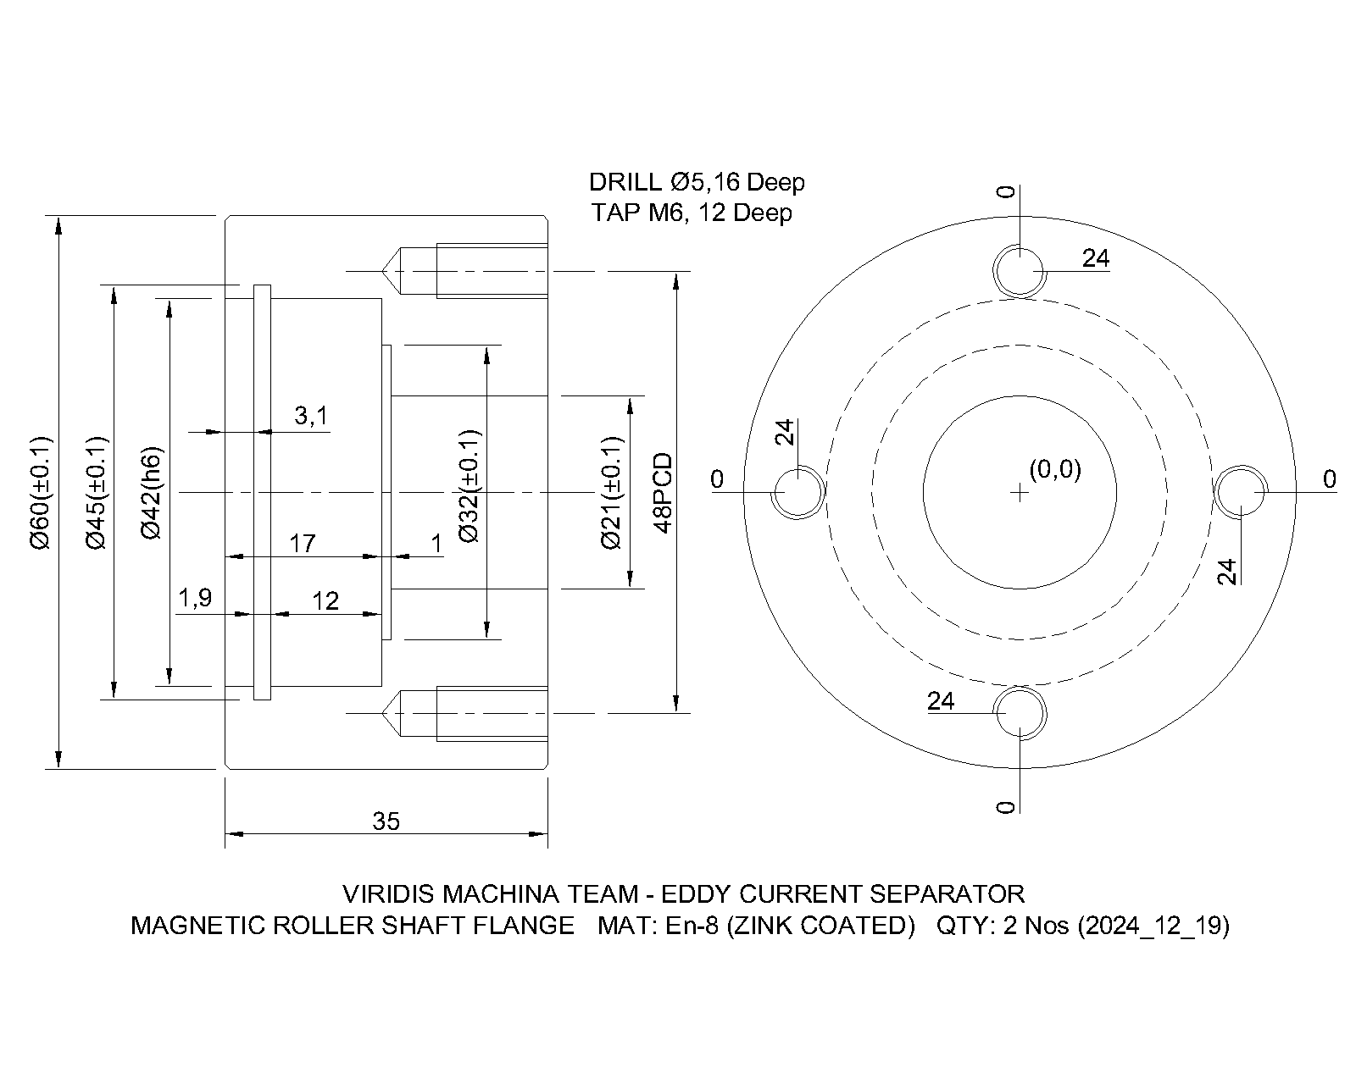
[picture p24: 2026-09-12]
cad/drawings/05-magnetic-roller-shaft-flange.png

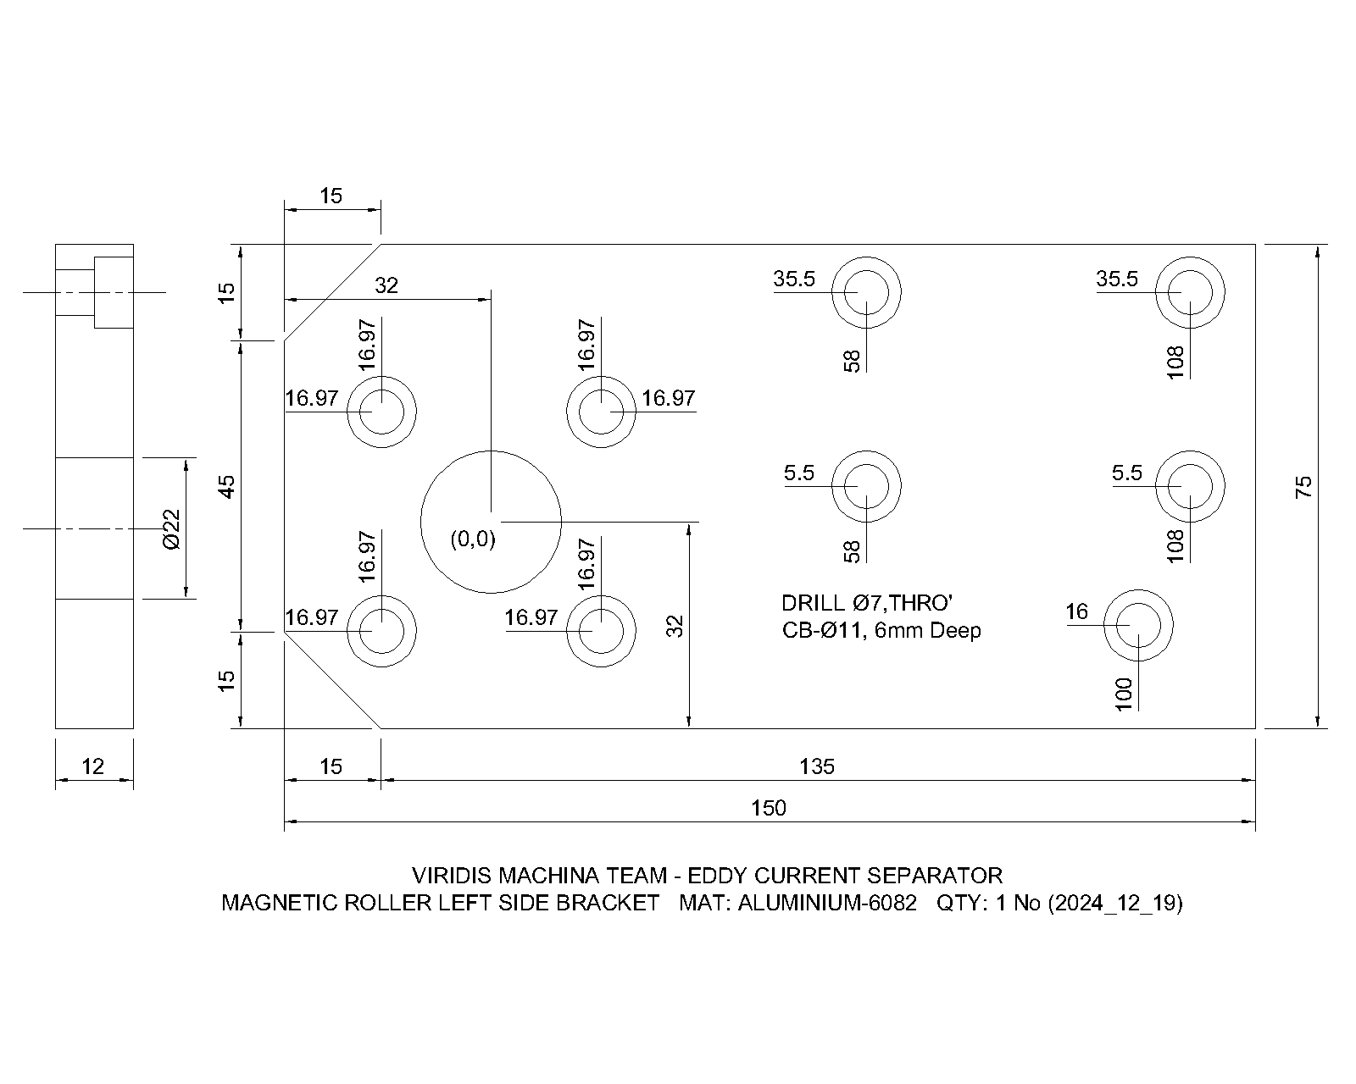
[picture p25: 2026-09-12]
cad/drawings/08-magnetic-roller-left-side-bracket.png

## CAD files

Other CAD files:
cad/source/eddy-current-separator.dwg
